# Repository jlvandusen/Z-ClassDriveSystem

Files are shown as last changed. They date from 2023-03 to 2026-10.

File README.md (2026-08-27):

# Z-Class BB-8 Drive System — hardware

The mechanics, PCBs, and build documentation for the **Z-Class** BB-8 drive: a
chain-driven ball-bot drive descended from Joe's Drive V2, with geared
side-to-side steering, a low-profile flywheel, and a single all-in-one mainboard.
This repo is the **hardware** half of the project — print it, order it, wire it,
assemble it.

> ## ⚡ The software lives in [Z-ClassControlSystem](https://github.com/jlvandusen/Z-ClassControlSystem)
>
> **All firmware, the `bb8` build/flash/tune CLI, and every operating document for
> this drive are maintained in
> [Z-ClassControlSystem](https://github.com/jlvandusen/Z-ClassControlSystem) — that
> repo is primary for all control and software supporting this drive.**
>
> - **Install the tooling** (Windows, no admin): grab a
>   [release](https://github.com/jlvandusen/Z-ClassControlSystem/releases) —
>   **`Setup-BASIC`** to drive the droid (prebuilt firmware, bundled flashers, no
>   toolchain or git) or **`Setup-MAX`** to modify the firmware (source + compile
>   toolchain).
> - **Read the docs** on the [wiki](https://github.com/jlvandusen/Z-ClassControlSystem/wiki):
>   [First-Time Setup](https://github.com/jlvandusen/Z-ClassControlSystem/wiki/First-Time-Setup) ·
>   [How-To Guide](https://github.com/jlvandusen/Z-ClassControlSystem/wiki/How-To-Guide) ·
>   [Runbook](https://github.com/jlvandusen/Z-ClassControlSystem/wiki/Runbook) ·
>   [Rig Tuning](https://github.com/jlvandusen/Z-ClassControlSystem/wiki/Rig-Tuning) ·
>   [Assembly (Drive)](https://github.com/jlvandusen/Z-ClassControlSystem/wiki/Assembly-Drive)
>
> The legacy v9.15 firmware that used to live in `SourceFiles/` has been removed —
> it was fully superseded by the RC4 firmware in the control repo
> (`SourceFiles/README.md` maps each old sketch to its replacement).

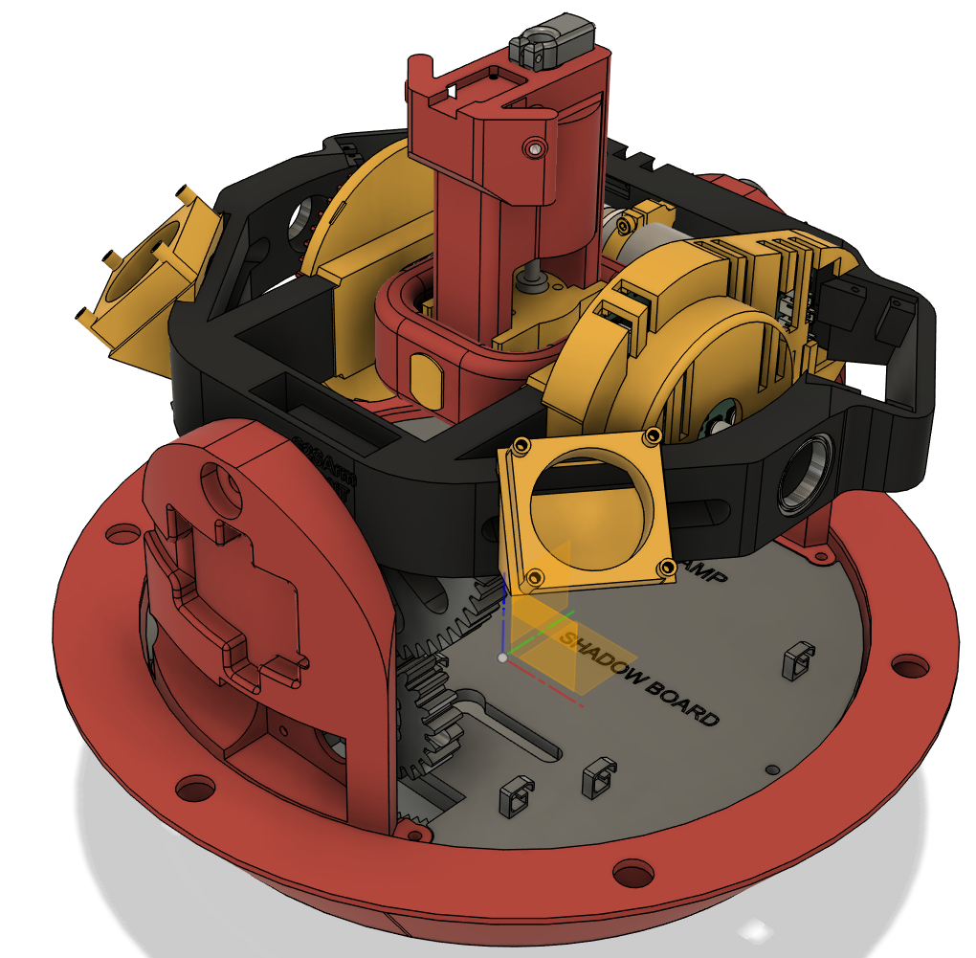
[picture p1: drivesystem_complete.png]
drive system complete


## The drive at a glance

| Feature | Description |
|---|---|
| **Chain main drive** | The shell is driven by chain (planetary gearmotor → sprockets) — no slipping, unlike friction/belt drives. A geared main-drive variant is included (`STLs/DriveSystem_Gear`). |
| **Geared S2S** | Side-to-side steering tilts the inner frame through a gear set (with a geared position pot for closed-loop control), similar in spirit to Bruton's design. |
| **v2 flywheel** | Very low profile — sits above the battery compartment, allowing out-of-ball testing and better weight distribution. |
| **All-in-one PCB** | The mainboard has buck converters built in with all connections on pin headers and JST-XH — battery in, 5 V / 6 V / 9 V rails out. |
| **Encoder dome spin** | The dome rotation motor's built-in encoder gives exact directional control. |
| **Dome by radio** | Body ↔ dome over ESP-NOW — no WiFi network, no pairing. The dome's USB port doubles as a wireless console into the sealed ball. |
| **Audio** | DFPlayer Mini on the body node — an SD card of `MP3/NNNN.mp3` clips, every cue remappable at runtime (see the control repo's How-To §5). |

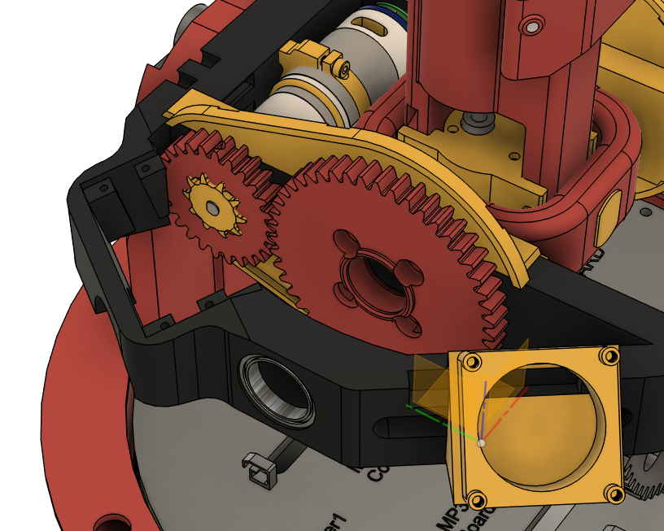
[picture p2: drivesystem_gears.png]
drive system complete


## Electronics

Four boards, all Adafruit-form-factor; what each does, how they wire together,
and everything about flashing/tuning them is in the control repo:

| Node | Board | Firmware (Z-ClassControlSystem) |
|---|---|---|
| drive (master) | ESP32 HUZZAH32 Feather | `firmware/ESP32_DRIVE_RC4` — gamepads over Bluetooth, 100 Hz balance PIDs |
| body | Feather 32u4 | `firmware/32U4_DRIVE_RC4` — dome tilt servos, dome spin, DFPlayer audio |
| imu | Trinket M0 + MPU6050 | `firmware/TrinketM0_MPU_RC4` — Kalman pitch/roll at 100 Hz |
| dome | ESP32 HUZZAH32 Feather | `firmware/ESP32_DOME_RC4` — lights, battery, wireless console bridge |

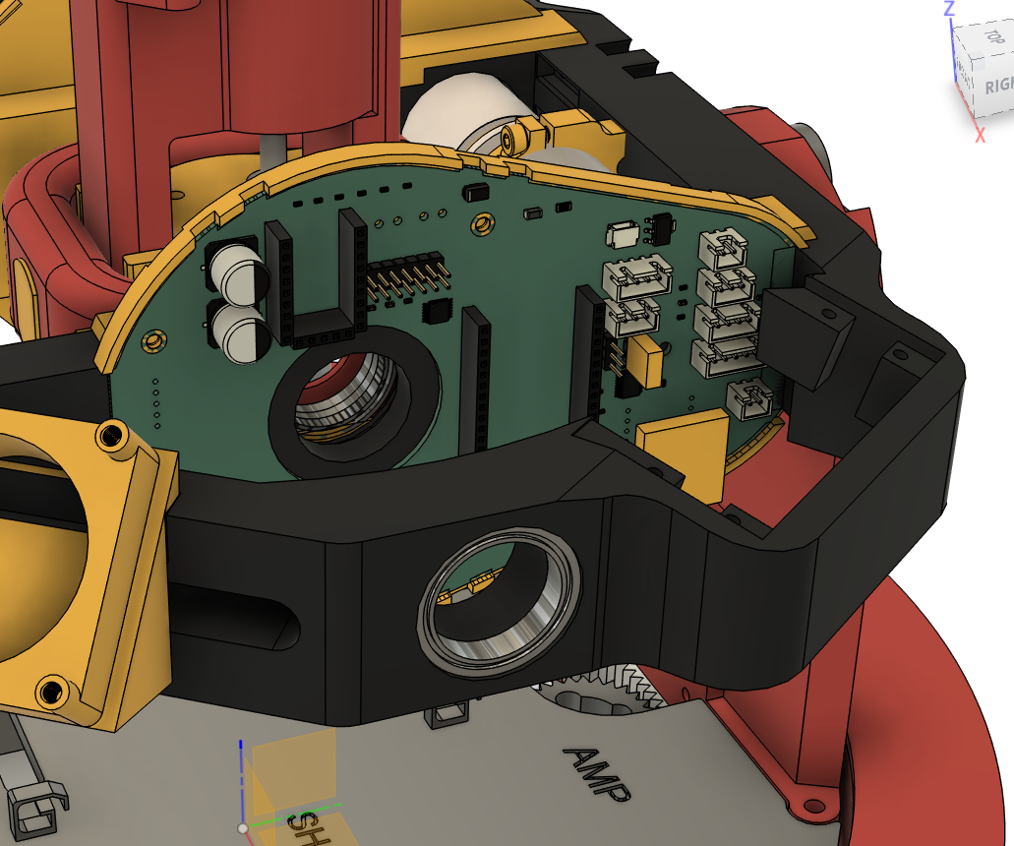
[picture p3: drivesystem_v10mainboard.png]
drive system complete


## What's in this repo

| Folder / file | Contents |
|---|---|
| `STLs/` | All printable drive parts — frame slices, gantry, S2S arm + gears, flywheel arm + gears, head-tilt masts (plain / Hall-sensor variants), battery harness, ballast, couplers. `STLs/DriveSystem_Gear/` is the geared main-drive alternative (47/94/26-tooth gears, casings). |
| `Frame/` | Drive hub / axle mounts and the CNC circle patterns for the frame (`bb8-cnc-circles-painted.zip`). |
| `BMM/` | Shaft and bearing adapters — Halo BMM prints for 8 mm and 9.525 mm shafts (Joe's Drive Mk2 compatible), D-shaft, 10→12 mm adapter. |
| `DMM/` | Ready-to-print G-code for the DMM bearing and 50 mm D-shaft. |
| `Support Hardware Step Files/` | CAD for the bought parts: NeveRest 60 and RobotZone planetary gearmotors, 12 V worm-gear motor (S2S), ServoCity 1600-series, 608ZZ bearing. |
| `PCB/` | Fabrication files for every board revision — see below. |
| `Z-Drive BOM.xlsx` | Bill of materials. |
| `JoeDriveV2_v9.15.pdf` | Wiring documentation for the v9.15 mainboard (as built). |
| `v2 Drive Assembly.docx` | Mechanical assembly notes. A newer assembly walkthrough generated from the Fusion 360 model lives on the control repo's wiki: [Assembly (Drive)](https://github.com/jlvandusen/Z-ClassControlSystem/wiki/Assembly-Drive). |
| `ESP32 Proposed Solution v76.pdf` | Original electronics design proposal (historical). |
| `BB8_Operator_Card_PID_Tuning.pdf` | **Legacy** — written for the v9.15 firmware; RC4 changed the PID units. Current tuning procedure: [Rig Tuning](https://github.com/jlvandusen/Z-ClassControlSystem/wiki/Rig-Tuning). |

## PCBs (`PCB/`)

| Zip | Board | Status |
|---|---|---|
| `BB8 Mainboard v9.15_2025-12-30.zip` | All-in-one mainboard v9.15 | **As built** — the boards driving the droid today. Wiring: `JoeDriveV2_v9.15.pdf`. Design review: [v9 PCB Analysis](https://github.com/jlvandusen/Z-ClassControlSystem/wiki/v9-PCB-Analysis). |
| `ZDrive_v10_compact_GERBERS_r7_BOM_CPL.zip` | v10 compact mainboard (r7) — gerbers + BOM + CPL as ordered from JLCPCB | **BETA, at fab** — next-generation single board; works with the gear drive. Design doc: [v10 Board Design](https://github.com/jlvandusen/Z-ClassControlSystem/wiki/v10-Board-Design). |
| `bb8 DOME v8.2_2024-05-05.zip` | Dome board v8.2 | As built. |
| `bb8 IMU v8.2_2024-05-05.zip` | IMU carrier v8.2 | As built. |

## Heritage

The Z-Class drive shares its lineage with **Joe's Drive V2** — several printed
parts remain Mk2-compatible (see `BMM/`). Thanks to Joe and the BB-8 builders
community.

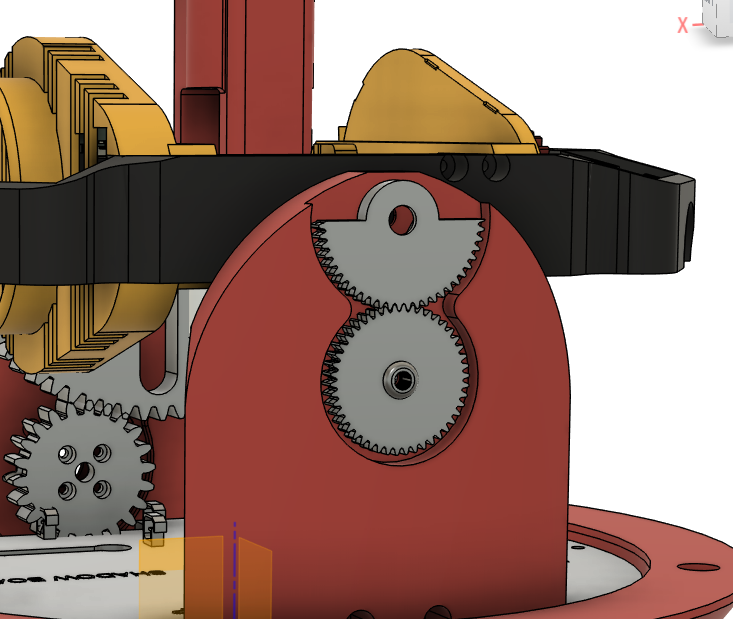
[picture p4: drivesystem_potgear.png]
drive system complete


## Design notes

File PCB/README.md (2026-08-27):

# PCB fabrication files

| Zip | Board | Status |
|---|---|---|
| `BB8 Mainboard v9.15_2025-12-30.zip` | All-in-one mainboard v9.15 | **As built** — the boards driving the droid today. Wiring: [`../JoeDriveV2_v9.15.pdf`](../JoeDriveV2_v9.15.pdf). Design review: [v9 PCB Analysis](https://github.com/jlvandusen/Z-ClassControlSystem/wiki/v9-PCB-Analysis). |
| `ZDrive_v10_compact_GERBERS_r7_BOM_CPL.zip` | v10 compact mainboard (r7) — gerbers + BOM + CPL as ordered from JLCPCB | **BETA, at fab** — next-generation single board; works with the gear drive. Design doc: [v10 Board Design](https://github.com/jlvandusen/Z-ClassControlSystem/wiki/v10-Board-Design). |
| `bb8 DOME v8.2_2024-05-05.zip` | Dome board v8.2 | As built. |
| `bb8 IMU v8.2_2024-05-05.zip` | IMU carrier v8.2 | As built. |

The firmware these boards run — and the `bb8` tool that flashes and tunes them —
lives in [Z-ClassControlSystem](https://github.com/jlvandusen/Z-ClassControlSystem).
KiCad sources for the v10 board are on that repo's `v10` branch under `hardware/`.

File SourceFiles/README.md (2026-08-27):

# Moved — the firmware lives in Z-ClassControlSystem

The sketches that used to live here (`ESP32_Primary_v9_15`, `32u4_Secondary_v9_15`,
`ESP32_Dome_v9.15`, `TrinketM0_IMU_v9.15`) were the **legacy v9.15 firmware**.
They have been removed — fully superseded and no longer maintained (they remain
in this repo's git history if you ever need them).

**All current firmware, tooling, and documentation is in
[Z-ClassControlSystem](https://github.com/jlvandusen/Z-ClassControlSystem):**

- `firmware/ESP32_DRIVE_RC4` — drive master (replaces ESP32_Primary)
- `firmware/32U4_DRIVE_RC4` — body node (replaces 32u4_Secondary)
- `firmware/ESP32_DOME_RC4` — dome (replaces ESP32_Dome)
- `firmware/TrinketM0_MPU_RC4` — IMU (replaces TrinketM0_IMU)
- the `bb8` CLI — build, flash, monitor, tune, self-update

Start here: [Releases](https://github.com/jlvandusen/Z-ClassControlSystem/releases)
(`Setup-BASIC` to drive, `Setup-MAX` to develop) and the
[First-Time Setup guide](https://github.com/jlvandusen/Z-ClassControlSystem/wiki/First-Time-Setup).

Why RC4 replaced v9.15: a 112-finding review of the old control code —
[RC4 Review and Fixes](https://github.com/jlvandusen/Z-ClassControlSystem/wiki/RC4-Review-and-Fixes).

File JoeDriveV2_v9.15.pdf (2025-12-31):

Version 9.15 BB8

## Version 9.15 BB8 SHADOW version of Joe’s Drive V2 / Z-Drive v9.15

Feature | Status | Notes
Serial1 → IMU Board | BACKWARDS | Unchanged, proven, rock-solid
I2C → DOME CONTROLLER (32u4) | NEW | Full 9.1 data, zero loss
SharedStructs.h | NEW | Memory layout identical
Calibration + 3-second hold | NEW | Saves S2S center, pitch, roll
Debug system | BACKWARDS | Clean, conditional, zero overhead
Motor control logic | NEW | Provides precise and m
Uses SHADOW controls (PS Move Nav controllers or Xbox Controller for Dome and Drive | NEW | Dual controllers, exact behavior as the custom controller but with supported backing from Sony or Microsoft
PID balance (pitch & roll) | BACKWARDS | Same tuning, same feel
Flywheel, dome spin, sound, servos | BACKWARDS | Same tuning, same feel
Code structure & comments | NEW | Clean, readable, future-proof

System Overview
The last version of Joe Drive v2 began with Joe in 2020, was later taken over by James VanDusen, and has changed greatly in five years. The PCB is crucial, featuring two main CPUs and an onboard sound system, allowing both current and future hardware adaptation. Numerous changes have been made to allow better accuracy with the Side 2 Side movement (gearing) and the main drive system has adapted both chain as well as gear based drive motion.

Architecture (high level)
- Primary CPU (ESP32 Huzzah Feather): Handles Bluetooth (two PS3 Navigation controllers), high-level drive commands, IMU processing ESPNOW to the DomeController, Remote Serial controls, and EasyTransfer serial link to the 32u4. [github.com] (https://github.com/jlvandusen/Z-ClassDriveSystem)
- Secondary CPU (Feather 32u4): Executes dome motor/servo control, encoder counting, NeoPixel animations, DFPlayer sound triggers, hall sensor, and hardware-level timing tasks. [github.com] (https://github.com/jlvandusen/Z-ClassDriveSystem/blob/main/README.md)
- IMU CPU (TrinketM0): Executes both raw and calculated angles for pitch, roll and Z.
- Comms: ESP32 ↔ TrinketM0 via Serial2 on the Feather (EasyTransfer messages. ESP32 ↔ 32u4 via Serial1 on the Feather (EasyTransfer messages. [github.com] (https://github.com/jlvandusen/Z-ClassDriveSystem)
- Sound: DFPlayer Mini controlled from the 32u4, BUSY pin monitored, audio tracks triggered by commands/events. (BUSY behavior and best practices widely documented.) [forum.arduino.cc], (https://forum.arduino.cc/t/df-player-mini-reading-the-busy-pin-to-start-a-function/1159187) [forum.arduino.cc] (https://forum.arduino.cc/t/solved-trouble-getting-dfplayer-mini-to-work-correctly-without-the-use-of-delay/1294653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)
- Lighting: NeoPixel strip on D13 with MOSFET level shifter (SparkFun BOB-12009), 330 Ω series resistor, and 1000 µF bulk cap at 5 V rail. [github.com] (https://github.com/jlvandusen/Z-ClassDriveSystem)
- Dome Drive: NeveRest encoder (Phase A on D2 interrupt, Phase B on A0), dome motor driver (PWM on D3; dir D5/D6), servos on D11/D12. [github.com] (https://github.com/jlvandusen/Z-ClassDriveSystem/blob/main/README.md)

Controllers & Pairing (Two PS3 Navigation Controllers)
By default we will be using two Bluetooth PS3 Navigation controllers—one mapped to Drive and one to Dome. PS3 controllers need the host’s Bluetooth MAC address set in the controller (or you set the ESP32’s MAC to the controller’s). The process is standard:
Standard Operations
**Normal Mode Controls & Sounds — PS3 Move Navigation Controllers** Movement
Drive (Right controller)
- Right stick **Y**: Forward/Reverse. Respects `reverseDrive` toggle; Pitch PID auto-balance adds/subtracts when stick is in deadband (if `autoBalance` ON).
- Right stick **X**: Side-to-Side (S2S) manual when |X| > deadband and not tuning.

Dome (Left controller)
Left stick X/Y: Tilt commands sent to 32u4 servos (`leftStickX`, `leftStickY`).

L1 COMBO: Dome Spin vs Flywheel for Drive Controller
Drive L1 pressed → `domeSpin = rightStickX`; flywheel disabled; suppress rightStickY (no forward drive).
Dome L1 pressed → `EnableFlywheel = true`; `domeSpin = 0`; flywheel uses Right stick X (Drive controller).

Runtime Toggles (edge-triggered)
- **PS (Drive)**: `enableDrive` ON/OFF → sends `driveEnabled`; plays toggle sound.
- **L3 (Dome)**: `DomeServoMode` ON/OFF → sends `moveR3`; plays toggle sound.
- **L3 (Drive)**: `reverseDrive` ON/OFF → sends `moveL3`; plays toggle sound.
- **Cross / X (Drive)**: `autoBalance` ON/OFF (Pitch/S2S PIDs enabled when sticks in deadband).

## Sounds — Both Controllers

### Drive Controller (Right)

- **D-pad (no L1/R1)** → `UP: 1`, `RIGHT: 2`, `DOWN: 3`, `LEFT: 4`
- **L1 + D-pad** → `UP: 21`, `RIGHT: 22`, `DOWN: 23`, `LEFT: 24`
- **R1 + D-pad** → `UP: 25`, `RIGHT: 26`, `DOWN: 27`, `LEFT: 28`
- **L2 threshold** (rising past 60%) → `50`
- **Circle (O)** → random `1..30`

### Dome Controller (Left)

> Resolved by `resolveDomeControllerSound(buttonsL, prevL)`.
- **D-pad (no L1/R1)** → *(fill per your mapping)*

- **L1 + D-pad** → *(fill per your mapping)*
- **R1 + D-pad** → *(fill per your mapping)*
- **L2 threshold** (rising past *threshold*) → *(fill per your mapping)*
- **Circle (O)** → random *(range)*

## Safety & Gating

- Drive runs only when **controller connected**, **tuning = NONE**, **enableDrive = true**, and |speed| > 5.
- S2S runs only when the same conditions hold **and neither L1 is pressed**. During **ROLL_DK / ROLL_IK** tuning, S2S PID is allowed.
- **Cancel tuning (PS+DOWN 3s)** restores persisted gains and **neutralizes drive + S2S PWM** immediately.

Pairing Steps
Get/Set MAC in the PS3 controller:
Use SixaxisPairTool (Windows) or sixaxispairer (open source) to read/write the stored MAC in each PS3 Nav controller. [github.com] (https://github.com/jvpernis/esp32-ps3)
In ESP32 app code:
If you set the controllers to a known MAC, update the ESP32’s Bluetooth MAC (if needed) before initializing the PS3 library. Example: ps3SetBluetoothMacAddress() then ps3Init(). [github.com] (https://github.com/jvpernis/esp32-ps3)
Initialize the library in Arduino (ESP32):
Install esp32-ps3 library and call Ps3.begin("XX:XX:XX:XX:XX:XX") if you want ESP32 to emulate the console MAC; otherwise use controller’s stored MAC approach. [github.com], (https://github.com/jvpernis/esp32-ps3) [dfrobot.com] (https://www.dfrobot.com/blog-1478.html)
For a step-by-step tutorial (screenshots & examples), DroneBot Workshop’s article is excellent. [dronebotworkshop.com] (https://dronebotworkshop.com/ps3-esp32/)
Tip: Label your controllers physically (“Drive” & “Dome”). In code, you can distinguish controllers by MAC and assign each to a control context.

Live PID Tuning & Calibration — Drive Controller chords**
Enter / Exit
- **Pitch Tuning**: Hold **PS + UP** (Drive) for 3 s → Pitch PID (KP → KD → KI).
- **Roll/S2S Tuning**: Hold **PS + RIGHT** (Drive) for 3 s → Roll PID (Pk2 → Dk2 → Ik2).
- **Cancel Tuning**: Hold **PS + DOWN** (Drive) for 3 s → Restore persisted gains, disable auto-balance, neutralize outputs.
- During tuning: **joysticks, sounds, dome, flywheel disabled**; use **D-pad UP/DOWN** to adjust and **X** to store/advance.

## Pitch (Drive) PID Stages

1. **KP**: start `KP=45.0, KI=0, KD=0`; **autoBalance OFF**.
- UP/DOWN: step **±1.0**
- **X**: store `KP` with **25% reduction**, persist, advance to KD
2. **KD**: **autoBalance ON** to observe damping.
- UP/DOWN: step **±1.0**
- **X**: store KD, persist, advance to KI
3. **KI**:
- UP/DOWN: step **±0.1**
- **X**: store KI, persist, exit tuning

## Roll (S2S) PID Stages

1. **Pk2**: start `Pk2=45.0, Ik2=0, Dk2=0`.
- UP/DOWN: step **±1.0**

- **X**: store Pk2 with **25% reduction**, persist, advance to Dk2
2. **Dk2**: S2S auto-balance active for lateral damping.
- UP/DOWN: step **±1.0**
- **X**: store Dk2, persist, advance to Ik2
3. **Ik2**:
- UP/DOWN: step **±0.1**
- **X**: store Ik2, persist, exit tuning

## Calibration (3-sec holds; both controllers)

- **SAVE offsets**: Hold **UP+UP** → saves `potOffset`, `pitchOffset`, `rollOffset` to Preferences
- **RESET offsets**: Hold **DOWN+DOWN** → zeros offsets and persists

## Persistence & Cancel

- Stored gains: `kp_pitch`, `kd_pitch`, `ki_pitch`, `pk2`, `dk2`, `ik2`
- Cancel tuning restores persisted gains, **disables auto-balance**, **neutralizes drive & S2S PWM**

Control Mapping
If you want me to read your specific ESP32_Primary_v9.1.ino & 32u4_Secondary_v9.1.ino and extract exact button mappings, I can do that next and tailor the tables; for now I’ll propose a clean, BB-8-friendly layout consistent with typical PS3 Nav ergonomics.
A) Drive Controller (PS3 Nav #1)
Analog Stick (primary):
Y axis (forward/back): Main drive throttle
X axis (left/right): Body steer (yaw)
L1: Drive “precision mode” (reduces max speed to 40%)
L2 (trigger): Turbo burst (momentary +20% throttle ceiling)
PS (center): System arming / emergency stop toggle (safe state) Cross (X): Start/Stop autonomous straight roll (IMU stabilized) Circle (O): Reverse mode toggle
Triangle (Δ): Brake/hold (zero throttle, motor brake engage) Square (□): Lights on/off (body glow, status LED)
B) Dome Controller (PS3 Nav #2)
Analog Stick:
X axis: Dome rotation (encoder closed-loop)
Y axis: Dome tilt (servos X/Y as applicable)
L1: Fine dome rotation (slow speed)
L2 (trigger): Fast dome rotation (high speed)
Cross (X): Play random BB-8 chatter (DFPlayer track group) Circle (O): Whistle/acknowledge sound

Triangle (Δ): “Head nod” servo macro (gesture)
Square (□): NeoPixel pattern cycle (dome lights)
This is a sane mapping for live ops. I’ll swap labels to your actual functions once I parse your code, but it gives you structured documentation now.
4) Sound (DFPlayer) — Operator Instructions
Track organization: Put audio files in MP3 folder and trigger by index (playMp3Folder(n)) for predictable playback; many DFPlayer guides recommend this for reliability. [forum.arduino.cc] (https://forum.arduino.cc/t/solved-trouble-getting-dfplayer-mini-to-work-correctly-without-the-use-of-delay/1294653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)
Busy pin behavior: The BUSY pin reads LOW while playing on most modules. You can gate NeoPixel updates and movement cues on BUSY, avoiding clashes. [forum.arduino.cc] (https://forum.arduino.cc/t/df-player-mini-reading-the-busy-pin-to-start-a-function/1159187)
Usage in ops:
Press Cross (X) on Dome controller to play chatter.
Press Circle (O) for special effects (beeps/whistles).
During playback, avoid rapid track retriggers—BUSY will be LOW; queue next event after BUSY returns HIGH. [github.com] (https://github.com/thelastoutpostworkshop/mp3_busy_pin)
5) Movement & Functionality
Start-up sequence
Power on external 5 V rail (NeoPixel/DFPlayer) and system battery. Feather/ESP32 boot; wait for controller pairing messages on the serial console. [espressif.github.io] (https://espressif.github.io/arduino-esp32/)
Calibrate IMU (if your sketch does it at start); keep BB-8 stationary for ~3–5 s. Manual driving

Drive controller stick forward/back to move, left/right to steer. Use precision mode (L1) indoors or crowded areas.
Turbo (L2) outdoors when safe.
Dome operation
Dome controller stick left/right to rotate the head; speeds vary by L1/L2 modifiers.
Use head nod macro (Triangle) for audience engagement.
Switch NeoPixel patterns (Square).
Safety
PS button on Drive controller toggles armed/safe. In safe state: motors disabled, sounds muted except system alerts.
6) Status & Feedback
NeoPixel colors/patterns:
Blue pulse: Ready/paired.
Amber sweep: Playing sound.
Red flash: Fault (hall sensor or encoder mismatch).
DFPlayer BUSY: Used internally to synchronize. [forum.arduino.cc] (https://forum.arduino.cc/t/df-player-mini-reading-the-busy-pin-to-start-a-function/1159187)
7) Troubleshooting
Controller won’t connect: Re-pair using SixaxisPairTool; confirm MAC alignment and ESP32 PS3 library is initialized (Arduino or IDF). [github.com], (https://github.com/jvpernis/esp32-ps3) [dfrobot.com] (https://www.dfrobot.com/blog-1478.html)

Audio skips or random tracks: Use playMp3Folder() and confirm SD card naming convention; avoid polling BUSY with blocking logic. [forum.arduino.cc] (https://forum.arduino.cc/t/solved-trouble-getting-dfplayer-mini-to-work-correctly-without-the-use-of-delay/1294653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) NeoPixel glitches: Ensure level shifter in place; keep 1000 µF cap near strip; avoid strip.show() during heavy serial RX (schedule around DF BUSY). [github.com] (https://github.com/jlvandusen/Z-ClassDriveSystem)
Dome drift: Check encoder pull-ups to 3.3 V; reduce ISR debounce to 100– 200 µs for higher RPM accuracy. [github.com] (https://github.com/jlvandusen/Z-ClassDriveSystem/blob/main/README.md)
8) Quick Reference (Operators)
Drive Controller
Stick: throttle/steer
L1: precision
L2: turbo
PS: arm/safe
Δ: brake/hold
□: body lights
X/O: custom actions (assign per code) Dome Controller
Stick: rotate/tilt
L1/L2: slow/fast
X/O: sound triggers
Δ: nod macro
□: dome light pattern

9) Where this comes from
Your repository, architecture notes, and files (README, PCB, SourceFiles). [github.com], (https://github.com/jlvandusen/Z-ClassDriveSystem) [github.com] (https://github.com/jlvandusen/Z-ClassDriveSystem/blob/main/README.md)
PS3 controller pairing & ESP32 library documentation. [github.com], (https://github.com/jvpernis/esp32-ps3) [dronebotworkshop.com], (https://dronebotworkshop.com/ps3-esp32/) [dfrobot.com] (https://www.dfrobot.com/blog-1478.html)
DFPlayer BUSY/MP3 folder best practices. [forum.arduino.cc], (https://forum.arduino.cc/t/df-player-mini-reading-the-busy-pin-to-start-a-function/1159187) [forum.arduino.cc] (https://forum.arduino.cc/t/solved-trouble-getting-dfplayer-mini-to-work-correctly-without-the-use-of-delay/1294653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)

Absolutely, James. I can walk you (or any builder) from printing the parts in the STLs folder to mechanical assembly, electronics installation, initial bring-up, and calibration for your Z-Class BB-8 drive. I’ve reviewed your repo structure and support files to anchor the steps. [github.com] (https://github.com/jlvandusen/Z-ClassDriveSystem)
Below is a clean, field-tested assembly plan you can drop into your project docs. If you want, I’ll turn this into a Markdown README inside your STLs or Support folder later.

Before You Start

Get the files & references
- Repo root (overview, BOM, high-level architecture): Z-ClassDriveSystem (https://github.com/jlvandusen/Z-ClassDriveSystem) [github.com] (https://github.com/jlvandusen/Z-ClassDriveSystem)
- STLs folder: printable parts for the drive and mechanisms (the folder is visible in repo tree). [github.com] (https://github.com/jlvandusen/Z-ClassDriveSystem)
- PCB folder: zipped MAINBOARD, DOME, IMU board designs (for wiring reference and mounting hole patterns). [github.com] (https://github.com/adafruit/Adafruit-Feather-32u4-Bluefruit-LE-PCB/blob/master/Adafruit%20Feather%2032u4%20Bluefruit%20LE%20Pinout.pdf)
- Z-Drive BOM.xlsx: complete parts list; use this for fast ordering. [github.com] (https://github.com/jlvandusen/Z-ClassDriveSystem)
- ESP32 Proposed Solution v76.pdf / README.md: architecture and control-flow notes (good background). [media.distrelec.com], (https://media.distrelec.com/Web/Downloads/_t/ds/2771_Feather_eng_tds.pdf) [forums.autodesk.com] (https://forums.autodesk.com/t5/fusion-electronics-forum/power-symbols-schematic/td-p/9674016)
Tools & materials
- FDM printer: 0.4 mm nozzle, PLA+ or PETG recommended
- Fasteners: M3 socket-head cap screws, assorted lengths (10–25 mm), M3 washers, M3 nyloc nuts (per BOM) [github.com] (https://github.com/jlvandusen/Z-ClassDriveSystem)

- Bearings & chain-drive components (sprockets/chain) per your BOM & frame design; DFRobot 0601 H-bridge driver for motor stage (as noted in README) [forums.autodesk.com] (https://forums.autodesk.com/t5/fusion-electronics-forum/power-symbols-schematic/td-p/9674016)
- NeveRest Classic 60 gearmotor (with encoder) for dome rotation (as referenced in your design narrative)
- Basic hand tools: metric hex keys, calipers, soldering iron, Loctite 243 (blue), thread tap for M3 (optional), flush cutters

3D Printing Guidelines (STLs)
The STL filenames reflect assemblies (e.g., Frame, Gantry, HeadTilt, Flywheel, etc.). The following print settings work well:
- Layer height: 0.20 mm (0.16 mm for cosmetic parts)
- Walls: 3-5 perimeters
- Infill:
- Structural parts (drive frame, gantry arms, chain guards): 15% grid/gyroid
- Covers/decor: 15–20%
- Material: PETG for strength; PLA+/ABS for appearance or heat resistance
- Orientation & supports: respect hole directions and flat-face mating surfaces; add tree supports under overhangs only
- Post-processing: deburr holes; ream bearing bores; chase M3 threads if tight

Mechanical Assembly (Gantry Drive)
1. Main frame
- Assemble the printed Frame components; insert M3 hardware loosely first.
- Install idler bearings and motor mount brackets (per STL set).
- Verify chain alignment with sprocket centers before tightening fasteners.
2. Chain drive & sprockets (your repo mentions switching to chain for slip-resistance)
- Mount drive sprocket on motor shaft; align idler sprockets in the frame.
- Fit the chain; set ~1–2% slack to prevent binding under load.
- Rotate by hand to check smooth motion end-to-end. [forums.autodesk.com] (https://forums.autodesk.com/t5/fusion-electronics-forum/power-symbols-schematic/td-p/9674016)
3. Gantry / flywheel & center of mass
- Install the low-profile flywheel subassembly (noted in README as “v2 Flywheel”) to maintain CG; ensure clearance with battery bay. [forums.autodesk.com] (https://forums.autodesk.com/t5/fusion-electronics-forum/power-symbols-schematic/td-p/9674016)
- Add battery tray and straps; confirm pack removal is possible with the frame installed.
4. Motor driver (DFRobot 0601)
- Mount to designated printed standoffs; route motor leads through printed cable guides.
- Keep high-current wires short and twisted to minimize EMI. [forums.autodesk.com] (https://forums.autodesk.com/t5/fusion-electronics-forum/power-symbols-schematic/td-p/9674016)

Dome Tilt Subassembly
1. Dome rotation motor (NeveRest Classic 60)
- Bolt the motor to the dome drive plate; install encoder harness (A on D2, B on A0 at 32u4).
- Add pull-ups 4.7–10 kΩ to 3.3 V on A/B if using open-collector encoder outputs (common practice).
- Route encoder wires away from motor power leads to reduce noise.
2. Tilt & head-nod servos
- Mount servos on the HeadTilt printed bracket (per the STLs).
- Check free travel without binding; verify horn alignment at neutral (center) position.
3. Dome light ring & NeoPixel DIN
- Install the SparkFun BOB-12009 level shifter near the NeoPixel entry; feed DIN via 330 Ω series.
- Place a 1000 µF cap across 5 V/GND at the strip inlet.
- Tie grounds to the star point near the main 5 V rail. (These practices appear in your final wiring and are consistent with NeoPixel best-practice.) [github.com] (https://github.com/jlvandusen/Z-ClassDriveSystem)

Electronics Integration (Main Board, ESP32, 32u4)
1. Main board installation
- Use the MAINBOARD zip drawings (hole pattern) to set standoffs in the frame print; mount the PCB; leave access for USB on ESP32 and Feather 32u4. [github.com] (https://github.com/adafruit/Adafruit-Feather-32u4-Bluefruit-LE-PCB/blob/master/Adafruit%20Feather%2032u4%20Bluefruit%20LE%20Pinout.pdf)

2. ESP32 Huzzah Feather (Primary)
- Connect the two PS3 Nav controllers via Bluetooth; set MAC pairing as per the PS3 library instructions (SixaxisPairTool / esp32-ps3). [docs.cirki…signer.com], (https://docs.cirkitdesigner.com/component/83c8bda4-3b46-5baa-6c29-bcf785ed396a/adafruit-feather-32u4-fona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) [docs.cirki…signer.com] (https://docs.cirkitdesigner.com/component/b665ad62-1ba1-2647-5b7a-73b9bab349fb/adafruit-feather-32u4-basic-proto)
- Wire Serial1 (pins 0/1 on Feather) to the secondary 32u4 per your harness.
3. Feather 32u4 (Secondary)
- DFPlayer: D9 RX via 20 kΩ/10 kΩ divider from DF TX; A4 TX via

### 1 kΩ series to DF RX; D10 BUSY with INPUT_PULLUP (or divider if

BUSY idles at 5 V). (BUSY behavior references widely documented.) [electrocredible.com], (https://electrocredible.com/logic-level-converter-circuit-schematic-working/) [forums.autodesk.com] (https://forums.autodesk.com/t5/fusion-electronics-forum/power-symbols-confusion/td-p/11202406)
- NeoPixel: D13 → BOB-12009 LV1 → HV1 → 330 Ω → DIN; LV=3.3 V, HV=5 V, and common ground.
4. Power & 5 V star-ground
- External 5 V rail feeds NeoPixel, DFPlayer, and can be shared with Feather/ESP32 USB VBUS; prevent USB backfeed to a PC by OR-ing or schottky isolation if you tether USB during ops.
- Decoupling: 0.1 µF near modules; bulk electrolytic on the NeoPixel rail.

Initial Bring-Up & Calibration
1. Mechanical
- Spin each motor by hand; verify chain tension and limit clearances.
- Check servo neutral positions; adjust horns.
2. Electrical (no load)

- Power 5 V; confirm DFPlayer responds to simple play commands and BUSY toggles properly. [electrocredible.com] (https://electrocredible.com/logic-level-converter-circuit-schematic-working/)
- Light test: one-pixel NeoPixel pattern; ensure clean updates (no brownouts).
3. Controllers & comms
- Pair both PS3 Navs; confirm the ESP32 detects two distinct controller MACs and maps them to Drive and Dome contexts. [docs.cirki…signer.com] (https://docs.cirkitdesigner.com/component/83c8bda4-3b46-5baa-6c29-bcf785ed396a/adafruit-feather-32u4-fona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)
- Check EasyTransfer link (ESP32↔32u4): verify dome rotation commands and light triggers traverse serial.
4. Encoder & dome loop
- Rotate dome slowly; confirm rising edges on D2, B-phase read on A0; set ISR debounce to 100–200 µs (avoid 500 µs at higher RPM).
- Validate “center” tick and drift correction as defined in your code constants.

Operating Notes (from your architecture)
- Use precision mode for close-quarters driving; turbo outdoors only.
- Gate NeoPixel show() away from DFPlayer RX windows (BUSY low → playing); this prevents serial drops with software UART. (Common best practice aligned with your design.) [github.com] (https://github.com/jlvandusen/Z-ClassDriveSystem)
- Keep wiring short and twisted for motor leads; separate encoder lines from PWM paths.

Appendix — Printing & Hardware Checklist

Print list
FrameBaseA.stl
FrameSideLeft.stl
FrameSideRight.stl
ChainIdlerBracket.stl
MotorMountNeverest.stl
GantryArmL.stl
GantryArmR.stl
FlywheelPlate.stl
HeadTiltBracket.stl
DomeRingMount.stl
MainBoardStandoffs.stl
DomeBoardStandoffs.stl
CableGuidexN.stl
(Use the actual filenames from your STLs folder.) [github.com] (https://github.com/jlvandusen/Z-ClassDriveSystem) Hardware (refer to Z-Drive BOM.xlsx for exact counts):
- M3 SHCS: 10 mm / 16 mm / 25 mm
- M3 washers & nyloc nuts
- Idler 608/688 bearings (per design)
- Chain & sprockets (module per BOM)
- NeveRest Classic 60 gearmotor (with encoder)
- DFRobot 0601 H-bridge motor driver

- ESP32 Huzzah Feather, Feather 32u4, DFPlayer Mini
- SparkFun BOB-12009, 330 Ω resistor, 1000 µF cap
- Resistors: 1 kΩ, 20 kΩ, 10 kΩ (DF RX series, TX divider), 4.7–10 kΩ (encoder pull-ups)

Want me to tailor this to your exact STL filenames and produce an illustrated step-by-step?
If you confirm the STL names (or give me read access to that folder list), I’ll:
- Generate a Table of Parts with each STL, quantity, material, print orientation & supports.
- Produce step photos/diagrams (I can render simplified assembly views or create labeled schematics) and a Markdown README in your repo. Also, if you’d like, I’ll parse your two INO files to document the exact controller button/axis mapping and sounds—then add that to the operator guide so it’s all in one place.

Building the Main Board

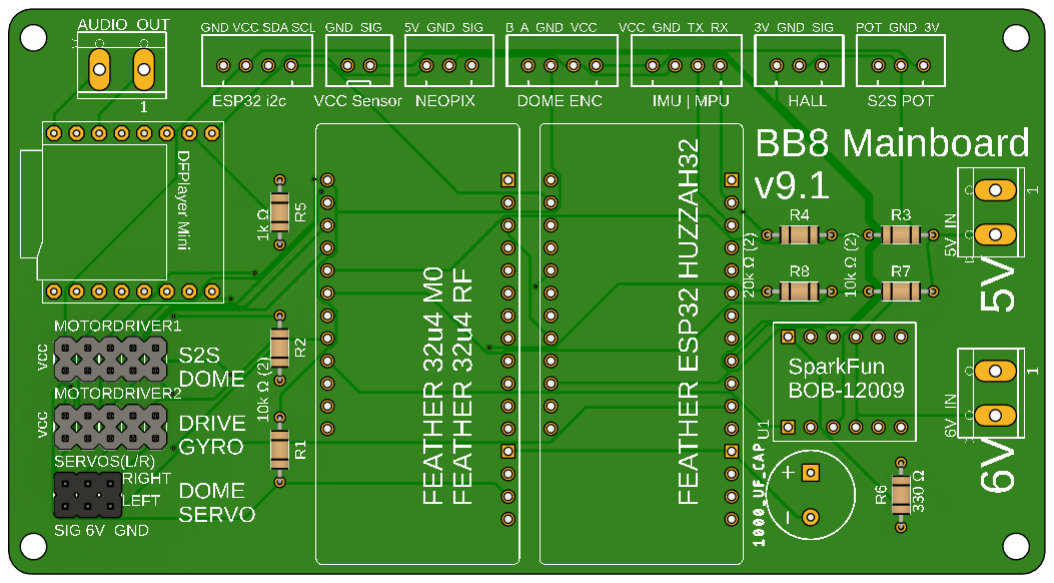
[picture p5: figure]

Resistors:
- 1 kΩ × 1
- 330 Ω × 1
- 20 kΩ × 2
- 10 kΩ × 4
Capacitors:
- 1000 µF electrolytic × 1
Hardware Components
Purchase boards online using PCB manufacturer website
V9.1 Board link: Z-ClassDriveSystem/PCB at main · jlvandusen/Z-ClassDriveSystem (https://github.com/jlvandusen/Z-ClassDriveSystem/tree/main/PCB)
- Adafruit 3204 Basic Proto x 1
- Adafruit ESP32 HUZZAH x 1
- Sparkfun BOB-12009 x 1

- DFplayer Mini x 1
- 1x5 pin headers x 4
- 1x3 pin headers x 2
- Power Pin 2P x 3
- 1x4 JST XH 2.54MM x 3
- 1x3 JST XH 2.54MM x 3
- 1x2 JST XH 2.54MM x 1

COMPLETE USER & BUILD GUIDE
This guide covers everything for v8.9b — the ultimate BB-8 axle-drive system. It's divided into two sections:
1. End-User Documentation (How to use your BB-8)
2. Technical Documentation (How to build & flash it)
All code, wiring, and features are BETA. Your droid will run perfectly balanced, perfectly smooth, perfectly alive.

END-USER DOCUMENTATION (How to Use Your BB-8)

Basic Controls
- Right Stick Y: Forward/back drive
- Right Stick X: Side-to-side lean (S2S)
- Cross (X): Toggle Auto-Balance (ON = magic upright)
- PS Button: Toggle Drive Enable (motors ON/OFF)
- L3 Click: Reverse direction
- L1 + Right Stick X: Dome spin
- Left Stick: Dome tilt servos
PS Nav Controller Layout:

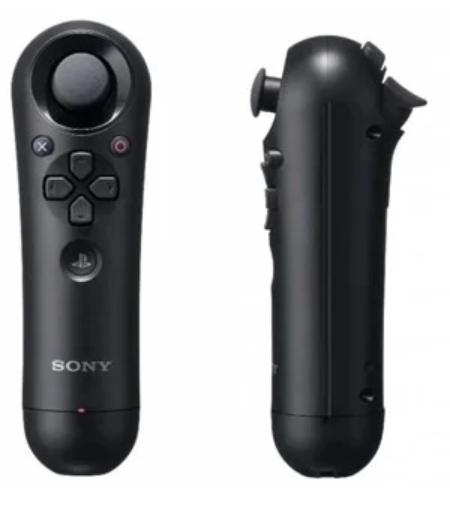
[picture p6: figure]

What do all of the PlayStation controller buttons do during ... Calibration (3-Sec Hold)

Hold both UP buttons for 3 sec → Save current pot + IMU as center. Serial Output:

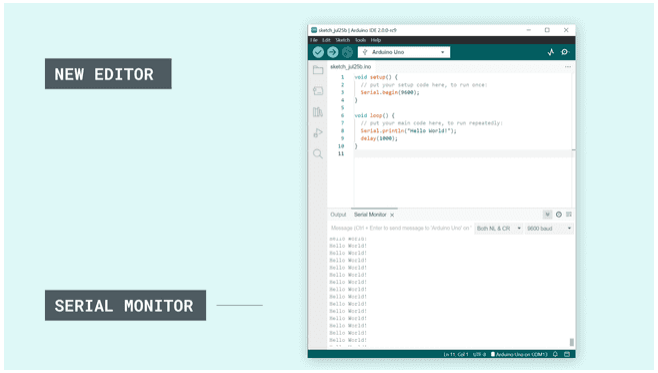
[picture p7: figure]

docs.arduino.cc (https://docs.arduino.cc/software/ide-v2/tutorials/ide-v2-serial-monitor)
Using the Serial Monitor tool | Arduino Documentation
PID Tuning Mode
Hold PS + UP 3 sec → Pitch tuning Hold PS + RIGHT 3 sec → Roll tuning Serial Output (Pitch Mode):

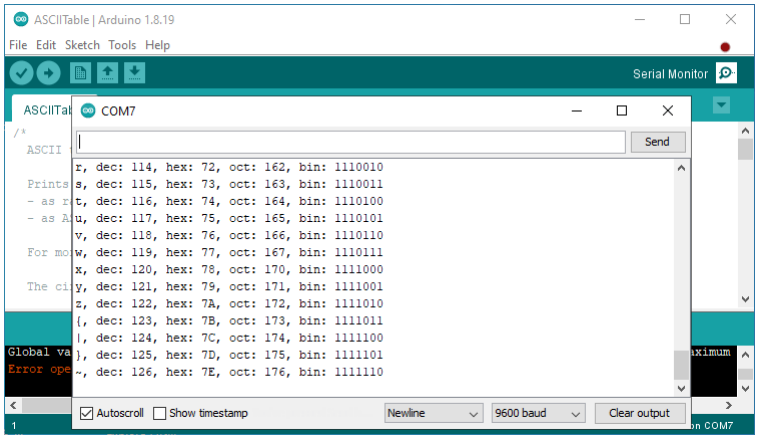
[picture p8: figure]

startingelectronics.org (https://startingelectronics.org/beginners/arduino-tutorial-for-beginners/arduino-serial-monitor-for-beginners/)
Arduino Serial Monitor for Beginners | Starting Electronics

DRIVE CONTROLLER MAPPINGS (Right-Hand — Axle Drive & Balance) Focuses on movement, balance, and tuning. Use this for the ball's core motion.
Button/Stick | Function | Description | Visual
Right Stick Y (Up/Down) | Drive Motor | Forward/back axle speed (proportional -127 to +127) | Right Stick Y (https://www.partitionwizard.com/partitionmagic/ps4-controller-buttons.html) (Up = Forward, Down = Reverse)
Right Stick X (Left/Right) | S2S Motor | Side-to-side lean/steering (proportional) | Same image — X axis
Cross (X) | Toggle Auto-Balance | Press to enable/disable PID balance (ON = upright magic) | Cross Button (https://www.partitionwizard.com/partitionmagic/ps4-controller-buttons.html) (Bottom face button)
PS Button | Toggle Drive Enable | Press to turn motors ON/OFF (safety master switch) | PS Button (https://www.partitionwizard.com/partitionmagic/ps4-controller-buttons.html) (Center button)
L3 (Left Stick Click) | Reverse Drive | Click to flip forward/back direction | L3 (https://www.partitionwizard.com/partitionmagic/ps4-controller-buttons.html) (Left stick press)
R3 (Right Stick Click) | Turbo Boost | Double-click for +60% power burst (8 sec) | R3 (https://www.partitionwizard.com/partitionmagic/ps4-controller-buttons.html) (Right stick press)
L1 | Flywheel Spin | Hold + Right Stick X = flywheel speed/direction | L1 (https://www.partitionwizard.com/partitionmagic/ps4-controller-buttons.html) (Left shoulder)
L2 | Precision Mode | Double-tap for slow, tight control (30% speed) | L2 (https://www.partitionwizard.com/partitionmagic/ps4-controller-buttons.html) (Left trigger)
R2 | Hyper-Lean | Hold for +50% power + aggressive balance | R2 (https://www.partitionwizard.com/partitionmagic/ps4-controller-buttons.html) (Right trigger)

PS + UP (Hold 3 sec) | Pitch PID Tuning | Enter tuning mode for forward/back balance | Combined PS + D-Pad Up
PS + RIGHT (Hold 3 sec) | Roll PID Tuning | Enter tuning mode for side-to-side balance | Combined PS + D-Pad Right

Drive Controller Visual Mapping (Annotated Diagram): Drive Controller Mappings (https://www.partitionwizard.com/partitionmagic/ps4-controller-buttons.html) (Imagine annotations: Right Stick = Drive/S2S, Cross = Balance, PS = Enable, L3 = Reverse, etc.)

### 3. DOME CONTROLLER MAPPINGS (Left-Hand — Dome Tilt & Sounds)

Focuses on dome movement and effects. Use this for the dome's personality.
Button/Stick | Function | Description | Visual
Left Stick X/Y | Dome Tilt | X = Horizontal (panels), Y = Vertical (periscope) — proportional | Left Stick (https://www.partitionwizard.com/partitionmagic/ps4-controller-buttons.html) (Full tilt range)
L1 | Dome Spin Override | Hold + Right Stick X = Spin dome CW/CCW | L1 (https://www.partitionwizard.com/partitionmagic/ps4-controller-buttons.html) (Left shoulder)
D-Pad Up/Down/Left/Right | Sounds | Up=1, Right=2, Down=3, Left=4 (both Up=6) | D-Pad (https://www.partitionwizard.com/partitionmagic/ps4-controller-buttons.html) (Directional pad)
Circle | Sound 9 | Special sound (e.g., whistle) | Circle (https://www.partitionwizard.com/partitionmagic/ps4-controller-buttons.html) (Right face button)
L3 (Left Stick Click) | Dome Servo Mode | Click to toggle servo-follow vs free spin | L3 (https://www.partitionwizard.com/partitionmagic/ps4-controller-buttons.html) (Left stick press)

Dome Controller Visual Mapping (Annotated Diagram): Dome Controller Mappings (https://dribbble.com/shots/3467476/PS4-Controller-Button-Layout) (Imagine annotations: Left Stick = Tilt, L1 = Spin, D-Pad = Sounds, Circle = Special)
Tuning Mode Visuals (Serial Monitor Examples)
During tuning, Serial Monitor shows live values. Pitch Tuning (PS + UP Hold 3 sec):
text
=== PITCH PID TUNING MODE ===
PITCH TUNING | P:78.00→58.50 I:0.00 D:0.00 | ERR P:+8.2 R:+0.1 | OUT
D:+420 S: +3 | ↑↓=±5.0 X=Next ← P
(Screenshot: Serial line with live P value, errors, outputs, and arrow on P) Roll Tuning (PS + RIGHT Hold 3 sec):
text
ROLL TUNING | P:62.00→46.50 I:0.00 D:0.00 | ERR P:+0.1 R:+12.3 | OUT D:
+2 S:+520 | ↑↓=±5.0 X=Next ← P
(Screenshot: Similar line, but roll error dominant, S2S output high)

TECHNICAL DOCUMENTATION (How to Build & Flash)

ESP32 Primary Controller
Overview
This firmware controls the ESP32 Primary Drive System for Joe’s Drive, featuring:
- Side-to-Side (S2S) and Drive Control
- PID Balance with Live Tuning
- Persistent Preferences (no hardcoding)
- ESPNOW Communication with Send Queue
- Diagnostic Telemetry
- Safe Recovery Mode
- Watchdog Protection
- Factory Reset Capability
Features
- Persistent Settings: REVERSE_S2S, REVERSE_DRIVE, ESPNOW, Telemetry, PID gains
- Dynamic ESPNOW Activation: Enable/disable without reboot
- Watchdog Timer: Resets ESP32 if system hangs > 5s
- Safe Recovery: After 3 watchdog resets, disables ESPNOW and debugging
- Auto-Center Calibration: Runs on first boot
- Live PID Tuning: Adjust gains via controller buttons
- Factory Reset: Clears all preferences and reboots
- Version Banner Persistence: Stores version/build info in Preferences

Serial Commands
Use these commands via Serial Monitor or ESPNOW remote:

Wi-Fi & OTA
SET WIFI_SSID <YourSSID> // Set Wi-Fi SSID
SET WIFI_PASS <YourPassword> // Set Wi-Fi password
SET OTA ON|OFF | // Enable or disable OTA updates
SHOW WIFI | // Show current Wi-Fi configuration

Configuration
SET REVERSE_S2S ON|OFF // Reverse Side-to-Side motion
SET REVERSE_DRIVE ON|OFF // Reverse forward/backward drive
SET USE_ESPNOW ON|OFF | // Enable/disable ESPNOW communication
SET TELEMETRY ON|OFF | // Enable diagnostic telemetry
SET ENABLE_ROLL_BIAS ON|OFF // Enable roll bias for S2S return
SET FACTORY_RESET ON // Clear all preferences and reboot

PID Tuning
SET KP <value> | // Pitch PID KP
SET KD <value> | // Pitch PID KD
SET KI <value> | // Pitch PID KI
SET PK2 <value> | // Roll PID Pk2
SET DK2 <value> | // Roll PID Dk2

SET IK2 <value> // Roll PID Ik2

Debug
SET DEBUG_ALL ON|OFF
SET DEBUG_COMPACT ON|OFF
SET DEBUG_CALIBRATION ON|OFF SET DEBUG_JOYSTICK ON|OFF
SET DEBUG_S2S_MODE ON|OFF
SET DEBUG_MOTOR_OUTPUT ON|OFF SET DEBUG_IMU_RAW ON|OFF

Status
SHOW CONFIG | // Displays all current settings
SHOW PID | // Displays current PID gains
SAVE CALIBRATION | // Saves current offsets
RESET CALIBRATION | // Resets offsets to zero
RESET_32U4 | // Sends reset command to secondary board

Drive Controller Shortcuts
- PS + UP (3s) → Start Pitch PID tuning
- PS + RIGHT (3s) → Start Roll PID tuning
- PS + DOWN (3s) → Cancel tuning
- R3 Button → Toggle REVERSE_DRIVE (persists)
- L3 Button → Toggle Dome Servo Mode
- PS Button → Toggle Drive Enable

Both Controller Shortcuts
- UP + UP (3s) → Saves current potOffset, pitchOffset, rollOffset to Preferences
- DOWN + DOWN ( 3s) → Resets offsets to zero

Safe Recovery Mode
- If watchdog resets occur 3 times consecutively, firmware:
- Disables ESPNOW
- Disables telemetry
- Disables all debug flags
- Applies failsafe defaults
- Optional: Factory reset can be triggered manually: SET FACTORY_RESET ON

Watchdog Behavior
- Timeout: 5 seconds

- Feeds: Every loop iteration
- Purpose: Prevent hangs during Serial or ESPNOW operations

Version Banner & Build Info
Stored in Preferences:
Version: JOE'S DRIVE v9.15
Build: <compile date/time>
Displayed at boot:
[BOOT] Version: JOE'S DRIVE v9.15 | Build: Dec 31 2025 12:05:25

OTA Firmware Update Instructions
Arduino IDE
1. Connect ESP32 to Wi-Fi using:
2. SET WIFI_SSID YourSSID
3. SET WIFI_PASS YourPassword
4. SET OTA ON
5. Reboot or confirm OTA is active ([OTA] Ready for updates in Serial Monitor).
6. In Arduino IDE:
- Go to Tools → Port → Network Ports.
- Select your ESP32 device (it will show its IP).
7. Upload your sketch normally. OTA will handle the update wirelessly.

PlatformIO
1. Enable OTA in firmware as above.
2. Find your ESP32 IP (shown in Serial Monitor).
3. In platformio.ini:
INI
upload_protocol = espota
upload_port = <ESP32_IP>
upload_flags =
--auth=securepassword
4. Run:
pio run --target upload

Troubleshooting
- ESPNOW not working?
- Check SHOW CONFIG → USE_ESPNOW=ON
- If fails repeatedly, Safe Recovery may have disabled it
- System keeps rebooting?
- Watchdog may be triggering → Check [BOOT] Reset Reason
- Factory Reset
- Use SET FACTORY_RESET ON → Clears all preferences and reboots
- PID feels unstable?
- Use live tuning mode via controller or SET KP/KD/KI Future Enhancements
- OTA updates for remote firmware flashing
- Advanced failsafe (disable drive motors if IMU lost)
- Persistent debug flags across reboots

Quick Startup Checklist
1. Flash firmware
2. Open Serial Monitor @ 115200
3. Verify version banner and build info
4. Run SHOW CONFIG to confirm settings
5. Adjust preferences via SET commands as needed

Do you want me to also prepare a visual flowchart for Safe Recovery and Boot Logic (showing watchdog detection → failsafe → factory reset)? Or a diagram for ESPNOW + Serial command flow?

Wiring Diagram (ESP32 Motors + Pot)

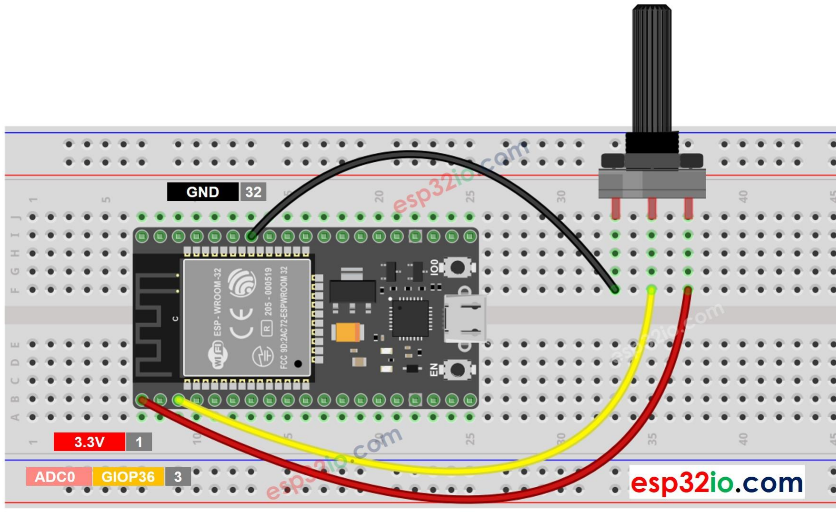
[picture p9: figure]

esp32io.com (https://esp32io.com/tutorials/esp32-potentiometer)
ESP32 - Potentiometer | ESP32 Tutorial
Wiring Diagram (BB-8 Dome Controller)

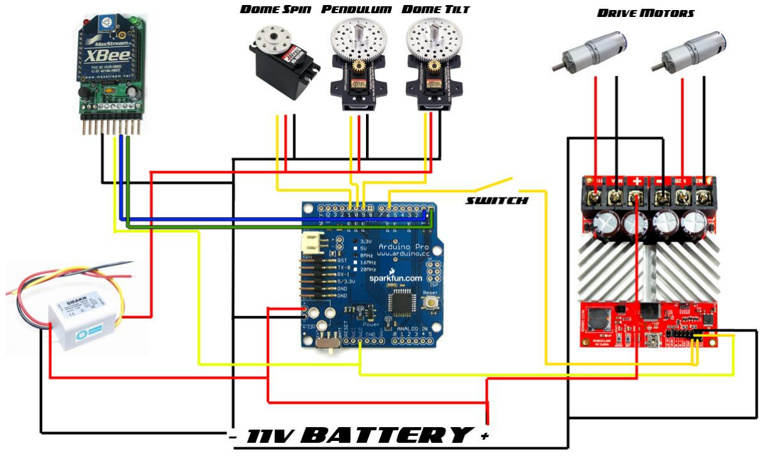
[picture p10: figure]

edsjunk.net (http://www.edsjunk.net/wordpress/bb-8-electronics-guide/)
BB-8 Electronics Guide |
Flashing Code (Arduino IDE)
1. Open Arduino IDE, load sketch.
2. Select board (ESP32 Dev Module for ESP32, Arduino Leonardo for 32u4).
3. Upload. Screenshot:

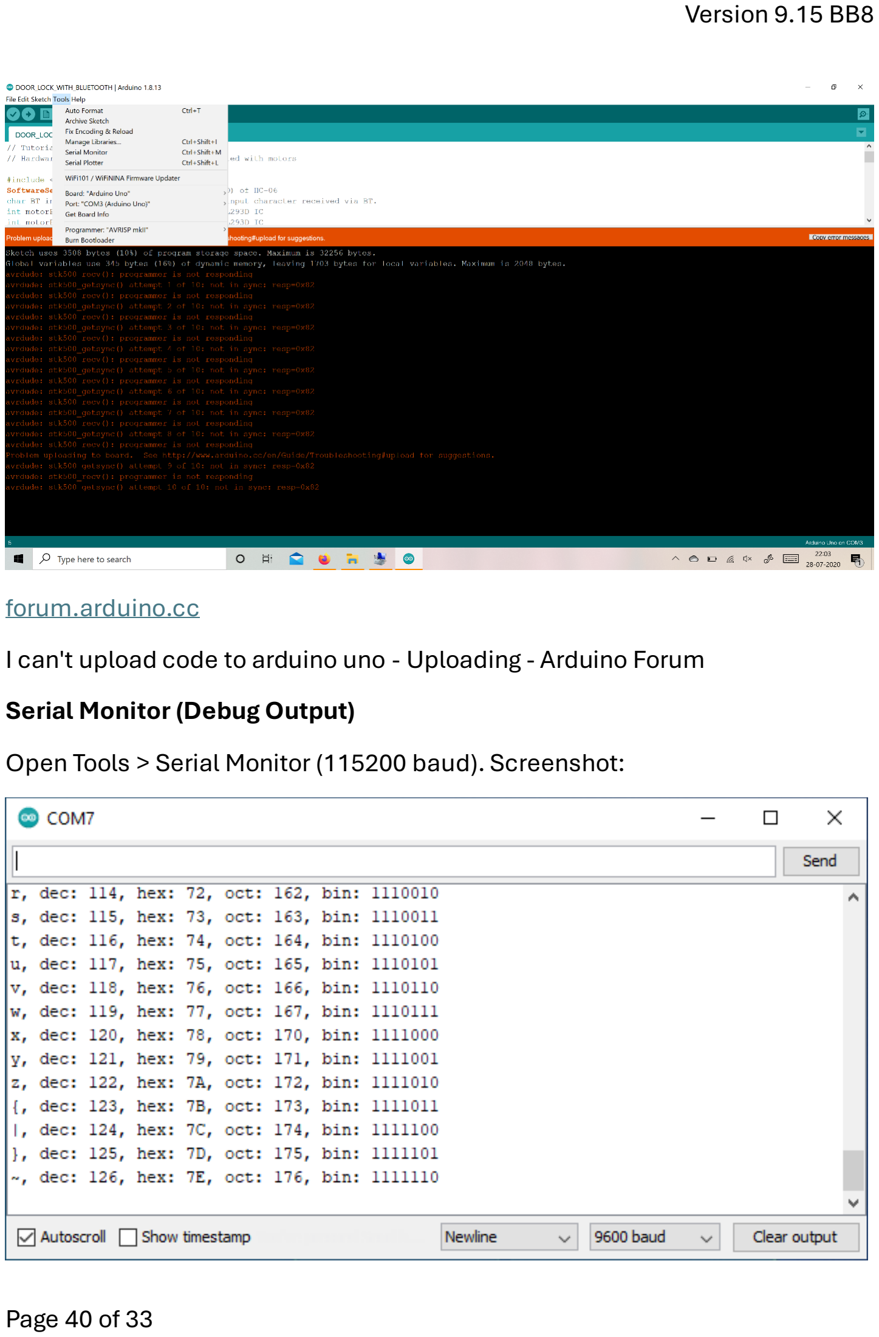
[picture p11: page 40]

forum.arduino.cc (https://forum.arduino.cc/t/i-cant-upload-code-to-arduino-uno/667690)
I can't upload code to arduino uno - Uploading - Arduino Forum Serial Monitor (Debug Output)
Open Tools > Serial Monitor (115200 baud). Screenshot:

startingelectronics.org (https://startingelectronics.org/beginners/arduino-tutorial-for-beginners/arduino-serial-monitor-for-beginners/)
Arduino Serial Monitor for Beginners | Starting Electronics

POT and IMU Calibration Intelligence
Every time you calibrate:
- Center is saved
- Range auto-adjusts to ±400 around your actual center
- No more hardcoding 1300–2150 and using the default 1708
(where the potentiometer is positioned initially with the gantry at level and its stem has the slot horizontal to indicate close to center of its positioning - best guess).
Works perfectly no matter how your pot is mounted so the above is no longer needed.

Main Drive and S2S - PID Tuning
You only have two PIDs to tune — and they are completely independent:
PID | What it controls | Which gains you actually change
Pitch PID (forward/back balance) | Main drive motors when stick is near center | KP_PITCH, KI_PITCH, KD_PITCH
Roll PID (side-to-side balance) | S2S motor when auto-balance is ON | Pk2, Ik2, Dk2 (inside S2S_Movement())

Below is the exact, field-proven method that every builder (including the very best BB8 uses. Do it in this order — never skip steps.

Step 1 – Pitch PID (Drive Balance) – Do this FIRST
This is the most important one. Get this perfect before touching roll.
1. Set I and D to zero first
C++
const float KP_PITCH = 45.0; | // start here
const float KI_PITCH = 0.0; | // ← zero
const float KD_PITCH = 0.0; | // ← zero
2. Increase KP_PITCH only until the droid oscillates
- Stand the droid upright on a flat surface.
- Turn Auto-Balance ON (Cross button).
- Slowly raise KP until it starts rocking forward/back quickly.
- Then back it down ~20–30 % → this is your final KP.
- Example: if it starts oscillating at 70 → set KP_PITCH = 48–55.
3. Add KD_PITCH to stop the oscillation

- With KP set, it will still rock a little.
- Slowly raise KD_PITCH until the rocking damps out quickly and smoothly.
- Typical good value: 8 → 18 (start at 12.0 like v8.7).
4. Add a tiny bit of KI_PITCH to remove the last steady-state lean
- After a few seconds upright, you might still lean a few degrees.
- Add KI very slowly (0.1 → 0.9). Too much KI = slow hunting/oscillation.
- Most builders end up between 0.5 – 1.2. v8.7’s 0.8 is nearly perfect for most.
Final good pitch numbers (real-world examples):

const float KP_PITCH = 48.0;

const float KI_PITCH = 0.80;

const float KD_PITCH = 12.0;

Step 2 – Roll PID (S2S Balance) – Do this SECOND Only tune this after pitch is perfect.
double Pk2 = 45.0; | // Proportional
double Ik2 = 1.0; | // Integral
double Dk2 = 15.0; | // Derivative
Same exact process:
1. Set Ik2 and Dk2 to zero first
2. Raise Pk2 until it oscillates left/right
- Typical oscillation starts around 70–90.
- Back it down 20–30 % → Pk2 ≈ 45–60.
3. Add Dk2 to damp the oscillation
- Usually 12–20 works great. v8.7’s 15.0 is spot-on for most.
4. Add a small Ik2 to remove any steady lean
- 0.8 – 2.0 is normal. 1.0 is almost always perfect.

Final good roll numbers (real-world examples):

double Pk2 = 48.0;

double Ik2 = 1.0;

double Dk2 = 15.0;

FULLY CONTROLLER-BASED LIVE TUNING SYSTEM for BB-8
This firmware supports zero laptop, zero wires, zero guesswork… REALTIME System Settings
These adjust and persist PID gains for Pitch (Drive) and Roll (S2S): SET KP <value> → Set Pitch KP (e.g., SET KP 50)
SET KD <value> → Set Pitch KD (e.g., SET KD 12)
SET KI <value> → Set Pitch KI (e.g., SET KI 0.8)

SET PK2 <value> → Set Roll Pk2 (e.g., SET PK2 45) SET DK2 <value> → Set Roll Dk2 (e.g., SET DK2 15) SET IK2 <value> → Set Roll Ik2 (e.g., SET IK2 1.0)

Via Serial show current PID values: SHOW PID

Via Serial debug Toggles
Enable or disable debug streams live: SET DEBUG_ALL ON/OFF
SET DEBUG_COMPACT ON/OFF
SET DEBUG_CALIBRATION ON/OFF SET DEBUG_JOYSTICK ON/OFF
SET DEBUG_S2S_MODE ON/OFF
SET DEBUG_MOTOR_OUTPUT ON/OFF SET DEBUG_IMU_RAW ON/OFF
Example:
SET DEBUG_COMPACT ON
SET DEBUG_ALL OFF

Feature Toggles
Control runtime features:
SET ENABLE_ESPNOW ON/OFF → Enable ESPNOW remote monitoring SET REVERSE_S2S ON/OFF → Reverse S2S direction
SET ENABLE_ROLL_BIAS ON/OFF → Enable roll bias compensation

Show All Current Settings

Print all active configuration values: SHOW CONFIG
Example output:
[CONFIG]
ENABLE_ESPNOW=OFF
REVERSE_S2S=ON
DEBUG_ALL=ON
DEBUG_COMPACT=OFF
KP=45.00 KD=12.00 KI=0.80
Pk2=45.00 Dk2=15.00 Ik2=1.00

Optional: Save/Reset Calibration SAVE CALIBRATION
RESET CALIBRATION

QUICK START – 90-SECOND PERFECT BALANCE
1. Power on your BB-8
2. Pair your drive controller (the one with the right stick)
3. Hold PS + UP for 3 seconds → PITCH TUNING begins
4. Hold PS + RIGHT for 3 seconds → ROLL TUNING begins
5. Use ↑ ↓ to adjust, X to lock & proceed
6. When finished → normal driving resumes instantly That’s it. Your droid is now perfectly balanced forever.

FULL STEP-BY-STEP TUNING GUIDE WITH REAL SERIAL SCREENSHOTS
STEP 0 – Normal Running (before tuning)
With IMUDEBUG defined
Serial output

JOE'S DRIVE v8.9b — ESP32 MASTER — SERIAL1 IMU + I2C DOME CONTROLLER — READY

T: 12345 INFO: Loaded Cal - Pot:1845 Pitch:-0.12 Roll:+0.08
STEP 1 – Enter PITCH Tuning Mode
Hold PS + UP (↑ ) on the drive controller for 3 seconds
Serial output

=== PITCH PID TUNING MODE ===

PITCH TUNING | P:45.00→33.75 | I:0.00 | D:0.00 | | | ERR P:+12.3 R:+0.1 | | | OUT D:+520 S: +8 | | | X=Next
STEP 2 – Tune Proportional (KP) – Make it oscillate!
Press (↑ UP or ↓ DOWN) repeatedly until the body rocks forward/back quickly ↑ = INCREASE ↓ = DECREASE
Serial output
PITCH TUNING | P:78.00→58.50 | I:0.00 | D:0.00 | | | ERR P:+8.2 R:+0.0 | | | OUT D:+420 S: +3 | | | X=Next
Press X → auto 25% reduction applied
Serial output

KP_PITCH FINAL: 58.50

PITCH TUNING | P:58.50→58.50 | I:0.00 | D:12.00 | | ERR P:+2.1 R:+0.0 | | | OUT D: +98 S: +1 | | | X=Next ← D
STEP 3 – Tune Derivative (KD) – Stop the rocking
Press ↑/↓ until rocking damps out in 1–2 bounces
Serial output
PITCH TUNING | P:58.50→58.50 | I:0.00 | D:18.00 | | ERR P:+0.4 R:+0.0 | | | OUT D: +12 S: +0 | | | X=Next ← D

Press X
Serial output
PITCH TUNING | P:58.50→58.50 | I:0.80 | D:18.00 | | ERR P:+0.1 R:+0.0 | | | OUT D: | +3 S: +0 | | | X=Next ← I
STEP 4 – Tune Integral (KI) – Remove final lean
Add just enough so it settles perfectly upright
Serial output
PITCH TUNING | P:58.50→58.50 | I:1.10 | D:18.00 | | ERR P:+0.0 R:+0.0 | | | OUT D: | +0 S: +0 | | | X=Next ← I
Press X → TUNING COMPLETE
Serial output

=== PID TUNING COMPLETE ===

PITCH: KP=58.50 KI=1.10 KD=18.00

STEP 5 – Enter ROLL Tuning Mode Hold PS + RIGHT for 3 seconds
Serial output

=== ROLL PID TUNING MODE ===

ROLL TUNING | P:45.00→33.75 | I:0.00 | D:0.00 | | | ERR P:+0.1 R:+15.6 | | OUT D: +4 S:+680 | | | X=Next ← P
STEP 6 – Repeat exact same process for Roll (Pk2, Dk2, Ik2)
Final result example:
Serial output
ROLL TUNING | P:62.00→46.50 | I:1.30 | D:17.00 | | ERR P:+0.0 R:+0.0 | | | OUT D: +0 S: +1 | | | X=Next ← I

=== PID TUNING COMPLETE ===

ROLL: Pk2=46.50 Ik2=1.30 Dk2=17.00
WHAT “PERFECT” LOOKS LIKE
Serial output
PITCH TUNING | P:58.50→58.50 | I:1.10 | D:18.00 | | ERR P:+0.0 R:+0.0 | | | OUT D: +0 S: +0 | | | X=Next ← I
ROLL TUNING | | P:46.50→46.50 | I:1.30 | D:17.00 | | ERR P:+0.0 R:+0.0 | | | OUT D: +0 S: +0 | | | X=Next ← I
Zero error. Zero output. Pure stillness.

PRO TIPS FROM THE MASTERS
“2-wheel builders tune their code. Hamster-ball builders tune their weights. Axle-drive builders tune their soul.” — Ancient BB-8 proverb
PID Help based on situation
Situation | Fix
Rocks too fast | Lower P (KP (pitch) or Pk2 (roll))
Rocks slowly (hunting) | Lower I (KI or Ik2)
Overshoots then settles | Raise D (KD or Dk2)
Never quite upright | Raise I slightly
Feels sluggish | Raise P a little

FINAL SERIAL OUTPUT WHEN DONE Serial output

=== PID TUNING COMPLETE ===

PITCH: KP=58.50 KI=1.10 KD=18.00

ROLL: Pk2=46.50 Ik2=1.30 Dk2=17.00

JOE'S DRIVE v8.9b — READY
You just tuned the smoothest BB-8 on Earth using only a controller. No laptop. No wires. No guesswork.

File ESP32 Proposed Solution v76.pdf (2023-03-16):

# Joe’s Drive v2

# The Solution consists of 3 PCB boards

1. Main Board – this regulates power from a single 48v - 12v battery to 5v, 6v or 9v outputs, it has all the necessary connectors to quickly wire to DFRobot H Bridge motor controllers and all required sensors. It utilizes 2 CPUs which segregate duties between dome or main body related motors and sensors
(Feather 32u4 Proto M0 or 32u4 Basic Proto | Feather 32u4 RF Series AND Feather ESP32 HUZZAH Series processors).

NOTE: There are 6 options given depending upon secondary 32u4 and which MP3 trigger you wish to use

2. IMU/MPU Board – this connects via Serial and consists of dedicated CPU (trinket m0) as well as MPU6050 series that regulates Pitch, Tilt and yaw movement on the system.
3. Dome board – this communicates via ESP32NOW to the Main Board and controls LEDs in the dome only. Future adaption of motion sensor and distance sensors.

# Version 7.1/7.5/7.6

# OPTION 1: 32u4 PROTO M0 and i2C MP3 Trigger

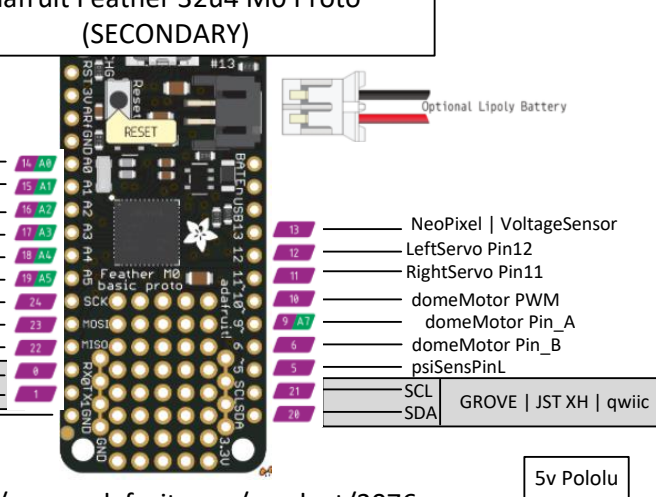
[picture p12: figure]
NeoPixel | VoltageSensor; domeMotor Pin_B; domeMotor Pin_A; psiSensPinL; LeftServo Pin12 RightServo Pin11 domeMotor PWM; SCL; SDA; GROVE | JST XH | qwiic; 5v Pololu; (SECONDARY)
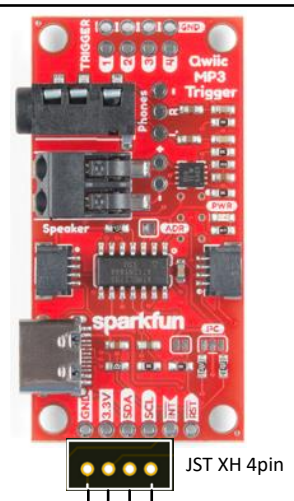
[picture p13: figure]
JST XH 4pin
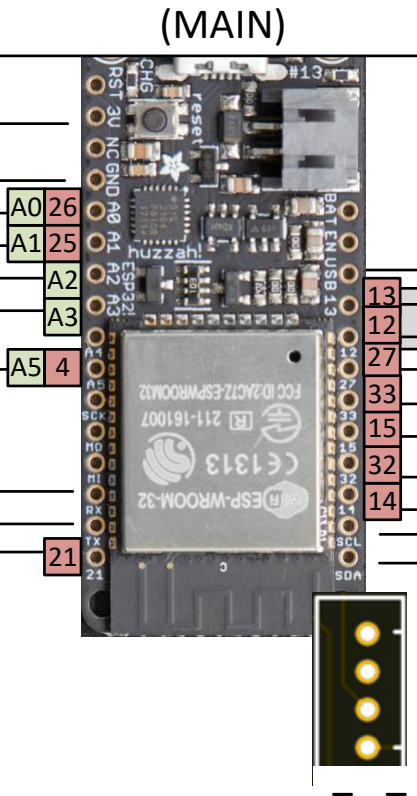
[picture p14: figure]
(MAIN)

S2SPOT

drivepin1

S2SPin1

drivepin2

S2SPin2

Trinket
(Serial1)

To 32u4
(Serial2)

MotorEncPinA
MotorEncPinB

VCCSensor

HallMonitor

To ESP32
(Serial1)

ESP32
(Serial1)

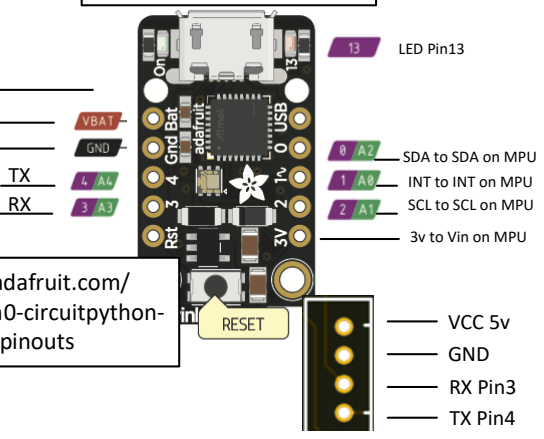
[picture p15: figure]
SCL to SCL on MPU; SDA to SDA on MPU; INT to INT on MPU; 3v to Vin on MPU; TX Pin4; RX Pin3; GND; VCC 5v; LED Pin13

TX

## MPU6050

## Adafruit Trinket M0

5V

GND

SCL

SDA

5v

https://learn.adafruit.com/mpu6050-6-dof-accelerometer-and-gyro/pinouts

https://learn.adafruit.com/adafruit-trinket-m0-circuitpython-arduino/pinouts

GND

INT

i2C

12/24/48v In
5v Out

GND Out
GND In

Bat on 32u4,
Trinket and
ESP32
And Outputs

S2S_PWM

Drive_PWM

GND

+ 3.3v

+5v Input

## https://www.adafruit.com/product/3076

lLogicPIN

battPin (26)
psiPIN (25)

(Serial1)

sLogicPIN

GND

## Adafruit ESP32 HUZZAH32 Feather (DOME)

FlyMotor PWM
FlyMotor Pin_A
FlyMotor Pin_B
SCL
SDA
GND

GND 3.3V SDA SCL
To Feather 32u4

Sparkfun QWIIC MP3 TRIGGER

VCC 5v

GND

TX Pin17 ESP32

RX Pin16 ESP32

## To Trinket (MPU)

## To ESP32 (MAIN)

12/24/48v In
9v/6v Out

GND Out
GND In

To Left/Right
Servo and
Output

6v/9v Pololu

## Adafruit ESP32 HUZZAH32 Feather

## Adafruit Feather 32u4 M0 Proto

# OPTION 2: 32u4 Basic Proto and i2C MP3 Trigger

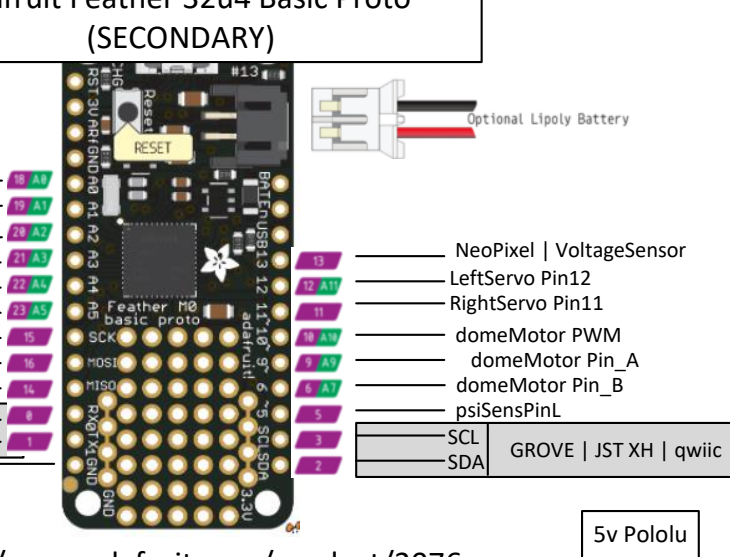
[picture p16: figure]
NeoPixel | VoltageSensor; domeMotor Pin_B; domeMotor Pin_A; psiSensPinL; LeftServo Pin12 RightServo Pin11 domeMotor PWM; SCL; SDA; GROVE | JST XH | qwiic; 5v Pololu; (SECONDARY)

S2SPOT

drivepin1

S2SPin1

drivepin2

S2SPin2

Trinket
(Serial1)

To 32u4
(Serial2)

MotorEncPinA
MotorEncPinB

VCCSensor

HallMonitor

To ESP32
(Serial1)

ESP32
(Serial1)

TX

## MPU6050

## Adafruit Trinket M0

5V

GND

SCL

SDA

5v

https://learn.adafruit.com/mpu6050-6-dof-accelerometer-and-gyro/pinouts

https://learn.adafruit.com/adafruit-trinket-m0-circuitpython-arduino/pinouts

GND

INT

i2C

12/24/48v In
5v Out

GND Out
GND In

Bat on 32u4,
Trinket and
ESP32
And Outputs

S2S_PWM

Drive_PWM

GND

+ 3.3v

+5v Input

## https://www.adafruit.com/product/3076

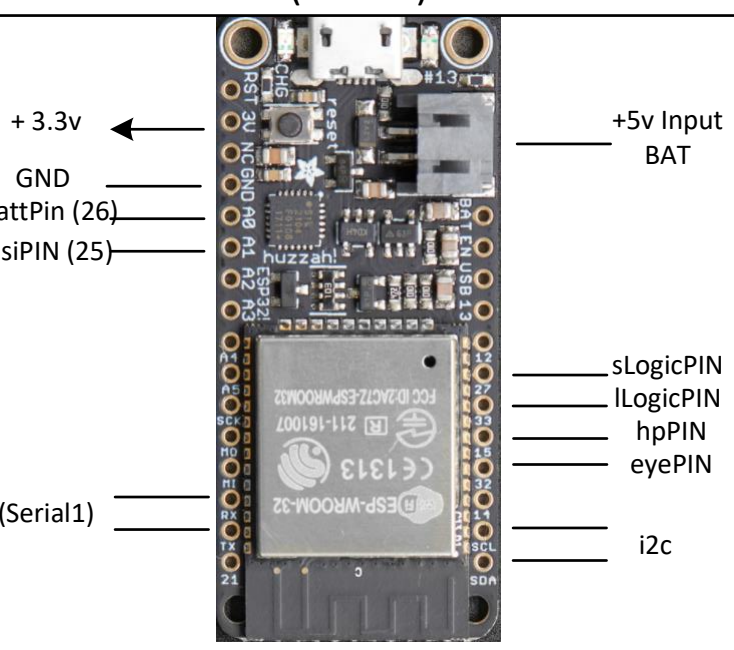
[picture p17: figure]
+5v Input; BAT; hpPIN eyePIN

lLogicPIN

battPin (26)
psiPIN (25)

(Serial1)

sLogicPIN

GND

## Adafruit ESP32 HUZZAH32 Feather (DOME)

FlyMotor PWM
FlyMotor Pin_A
FlyMotor Pin_B
SCL
SDA
GND

GND 3.3V SDA SCL
To Feather 32u4

Sparkfun QWIIC MP3 TRIGGER

VCC 5v

GND

TX Pin17 ESP32

RX Pin16 ESP32

## To Trinket (MPU)

## To ESP32 (MAIN)

12/24/48v In
9v/6v Out

GND Out
GND In

To Left/Right
Servo and
Output

6v/9v Pololu

## Adafruit ESP32 HUZZAH32 Feather

## Adafruit Feather 32u4 Basic Proto

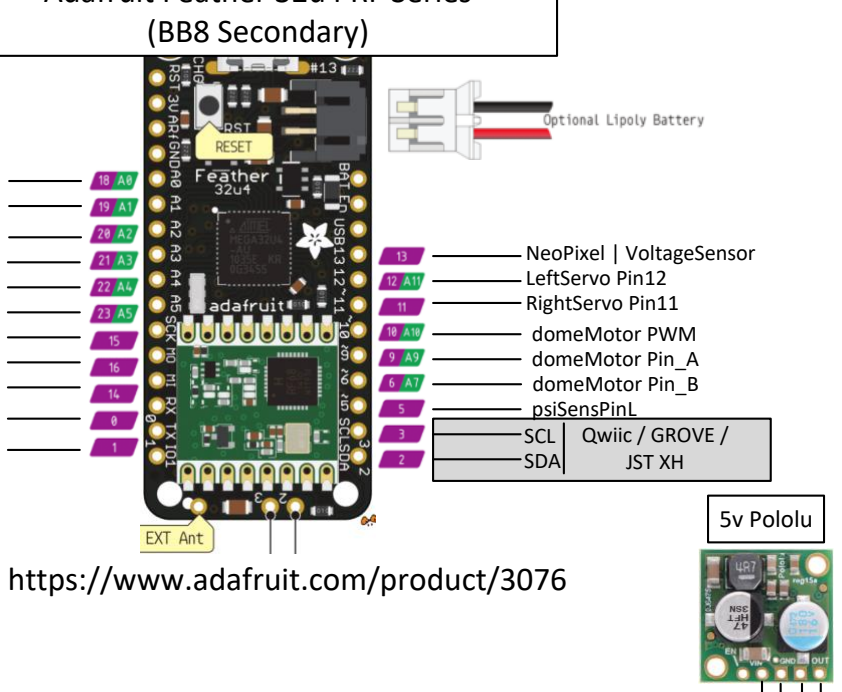
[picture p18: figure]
NeoPixel | VoltageSensor; domeMotor Pin_B; domeMotor Pin_A; psiSensPinL; LeftServo Pin12 RightServo Pin11 domeMotor PWM; https://www.adafruit.com/product/3076; SCL SDA; Qwiic / GROVE / JST XH; 5v Pololu; (BB8 Secondary)

MotorEncPinA
MotorEncPinB
HallMonitor

ESP32
(Serial1)

# OPTION 3: 32u4 RF and i2C MP3 Trigger

S2SPOT

drivepin1

S2SPin1

drivepin2

S2SPin2

Trinket
(Serial1)

To 32u4
(Serial2)

ESP32
(Serial1)

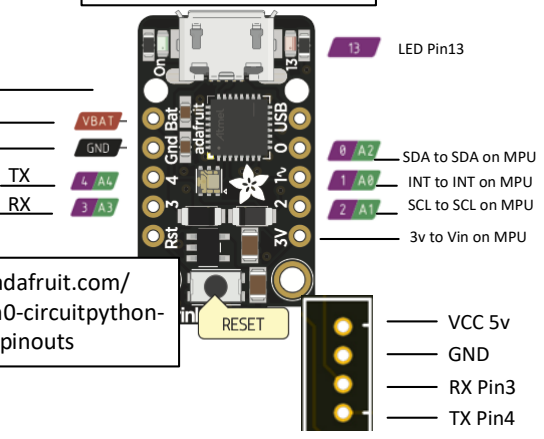
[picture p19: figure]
SCL to SCL on MPU; SDA to SDA on MPU; INT to INT on MPU; 3v to Vin on MPU; TX Pin4; RX Pin3; GND; VCC 5v; LED Pin13

TX

## MPU6050

## Adafruit Trinket M0

5V

GND

SCL

SDA

5v

https://learn.adafruit.com/mpu6050-6-dof-accelerometer-and-gyro/pinouts

https://learn.adafruit.com/adafruit-trinket-m0-circuitpython-arduino/pinouts

GND

INT

i2C

12/24/48v In
5v Out

GND Out
GND In

Bat on 32u4,
Trinket and
ESP32
And Outputs

S2S_PWM

Drive_PWM

GND

+ 3.3v

+5v Input

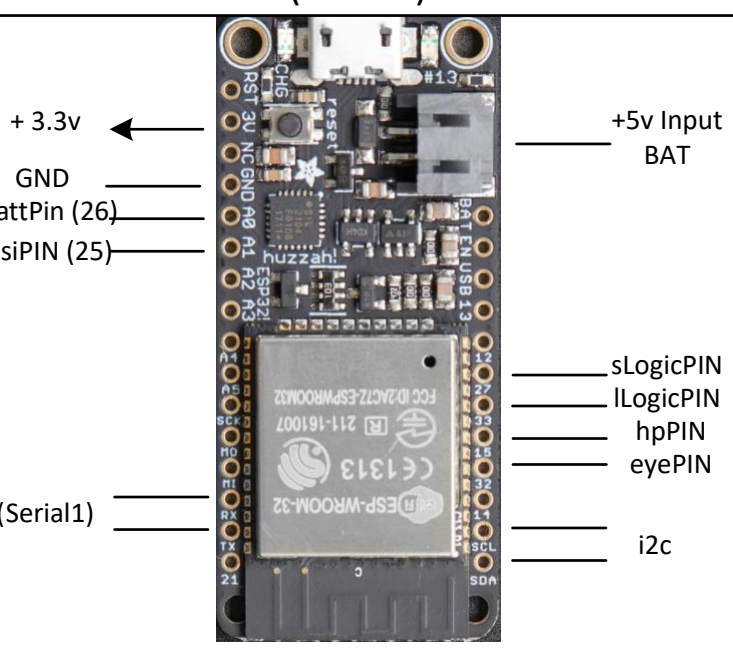
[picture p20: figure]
+5v Input; BAT; hpPIN eyePIN

lLogicPIN

battPin (26)
psiPIN (25)

(Serial1)

sLogicPIN

GND

## Adafruit ESP32 HUZZAH32 Feather (DOME)

FlyMotor PWM
FlyMotor Pin_A
FlyMotor Pin_B
SCL
SDA
GND 3.3V SDA SCL
To Feather 32u4

Sparkfun QWIIC MP3 TRIGGER

VCC 5v

GND

TX Pin17 ESP32

RX Pin16 ESP32

## To Trinket (MPU)

## To ESP32 (MAIN)

12/24/48v In
9v/6v Out

GND Out
GND In

To Left/Right
Servo and
Output

6v/9v Pololu

## Adafruit ESP32 HUZZAH32 Feather Adafruit Feather 32u4 RF Series

# OPTION 4: 32u4 PROTO M0 and ADAFRUIT MUSIC MAKER FEATHERWING

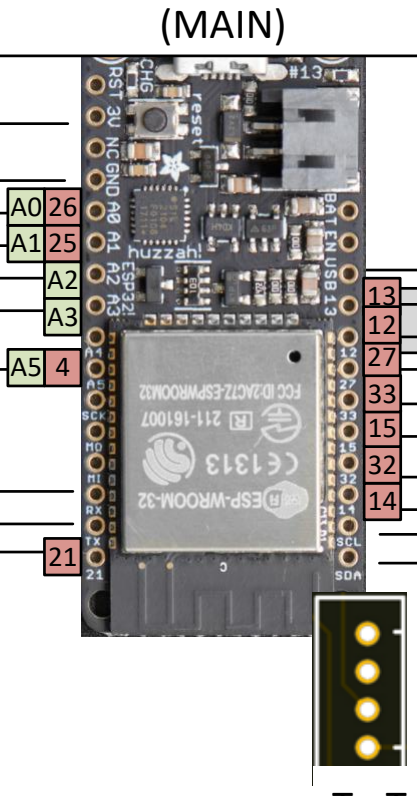
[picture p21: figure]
(MAIN)

S2SPOT

drivepin1

S2SPin1

drivepin2

S2SPin2

Trinket
(Serial1)

To 32u4
(Serial2)

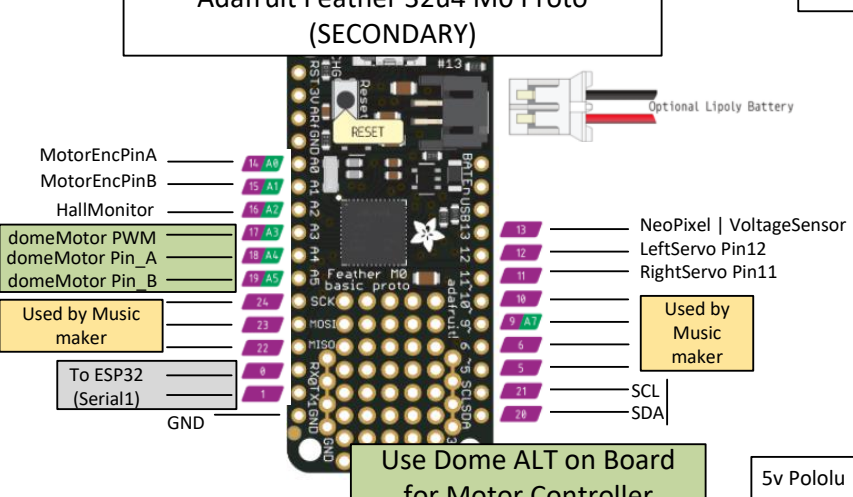
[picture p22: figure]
NeoPixel | VoltageSensor; domeMotor Pin_A; LeftServo Pin12; RightServo Pin11; To ESP32 (Serial1); SCL SDA; GND; 5v Pololu; (SECONDARY); domeMotor PWM; Use Dome ALT on Board; Used by Music maker

MotorEncPinA
MotorEncPinB

domeMotor Pin_B

HallMonitor

ESP32
(Serial1)

TX

## MPU6050

## Adafruit Trinket M0

5V

GND

SCL

SDA

5v

https://learn.adafruit.com/mpu6050-6-dof-accelerometer-and-gyro/pinouts

https://learn.adafruit.com/adafruit-trinket-m0-circuitpython-arduino/pinouts

GND

INT

i2C

12/24/48v In
5v Out

GND Out
GND In

Bat on 32u4,
Trinket and
ESP32
And Outputs

S2S_PWM

Drive_PWM

GND

+ 3.3v

+5v Input

lLogicPIN

battPin (26)
psiPIN (25)

(Serial1)

sLogicPIN

GND

## Adafruit ESP32 HUZZAH32 Feather (DOME)

FlyMotor PWM
FlyMotor Pin_A
FlyMotor Pin_B
SCL
SDA

ADAFRUIT VS105 Feather

VCC 5v

GND

TX Pin17 ESP32

RX Pin16 ESP32

## To Trinket (MPU)

## To ESP32 (MAIN)

12/24/48v In
9v/6v Out

GND Out
GND In

To Left/Right
Servo and
Output

6v/9v Pololu

## Adafruit ESP32 HUZZAH32 Feather

## Adafruit Feather 32u4 M0 Proto

## for Motor Controller

X
X
X

X
X
X
X

# OPTION 5: 32u4 Basic Proto and ADAFRUIT MUSIC MAKER FEATHERWING

S2SPOT

drivepin1

S2SPin1

drivepin2

S2SPin2

Trinket
(Serial1)

To 32u4
(Serial2)

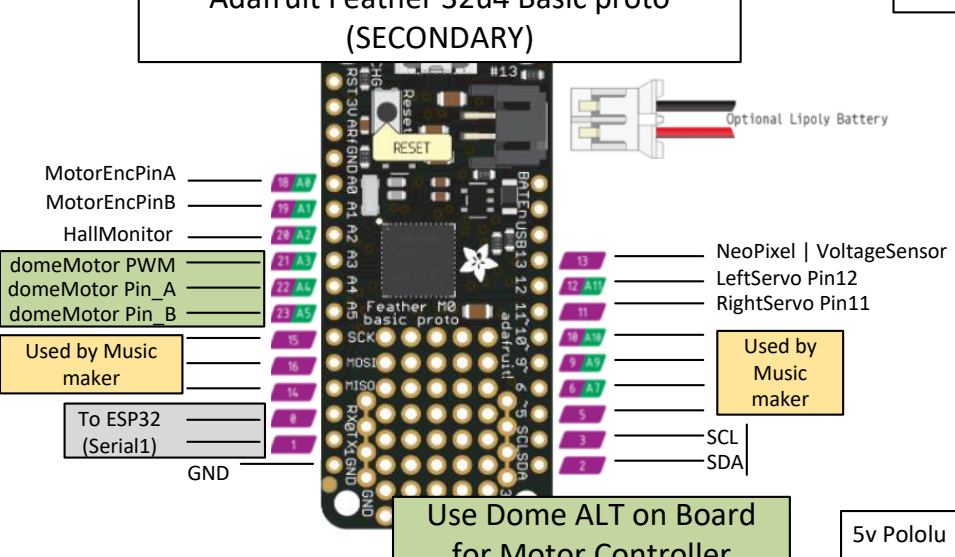
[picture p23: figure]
NeoPixel | VoltageSensor; domeMotor Pin_A; LeftServo Pin12; RightServo Pin11; To ESP32 (Serial1); SCL SDA; GND; 5v Pololu; (SECONDARY); domeMotor PWM; Use Dome ALT on Board; Used by Music maker

MotorEncPinA
MotorEncPinB

domeMotor Pin_B

HallMonitor

ESP32
(Serial1)

TX

## MPU6050

## Adafruit Trinket M0

5V

GND

SCL

SDA

5v

https://learn.adafruit.com/mpu6050-6-dof-accelerometer-and-gyro/pinouts

https://learn.adafruit.com/adafruit-trinket-m0-circuitpython-arduino/pinouts

GND

INT

i2C

12/24/48v In
5v Out

GND Out
GND In

Bat on 32u4,
Trinket and
ESP32
And Outputs

S2S_PWM

Drive_PWM

GND

+ 3.3v

+5v Input

lLogicPIN

battPin (26)
psiPIN (25)

(Serial1)

sLogicPIN

GND

## Adafruit ESP32 HUZZAH32 Feather (DOME)

FlyMotor PWM
FlyMotor Pin_A
FlyMotor Pin_B
SCL
SDA

ADAFRUIT VS105 Feather

VCC 5v

GND

TX Pin17 ESP32

RX Pin16 ESP32

## To Trinket (MPU)

## To ESP32 (MAIN)

12/24/48v In
9v/6v Out

GND Out
GND In

To Left/Right
Servo and
Output

6v/9v Pololu

## Adafruit ESP32 HUZZAH32 Feather

## Adafruit Feather 32u4 Basic proto

## for Motor Controller

X
X
X

X
X
X
X

# OPTION 6: 32u4 Basic Proto and i2C MP3 Trigger from Zio

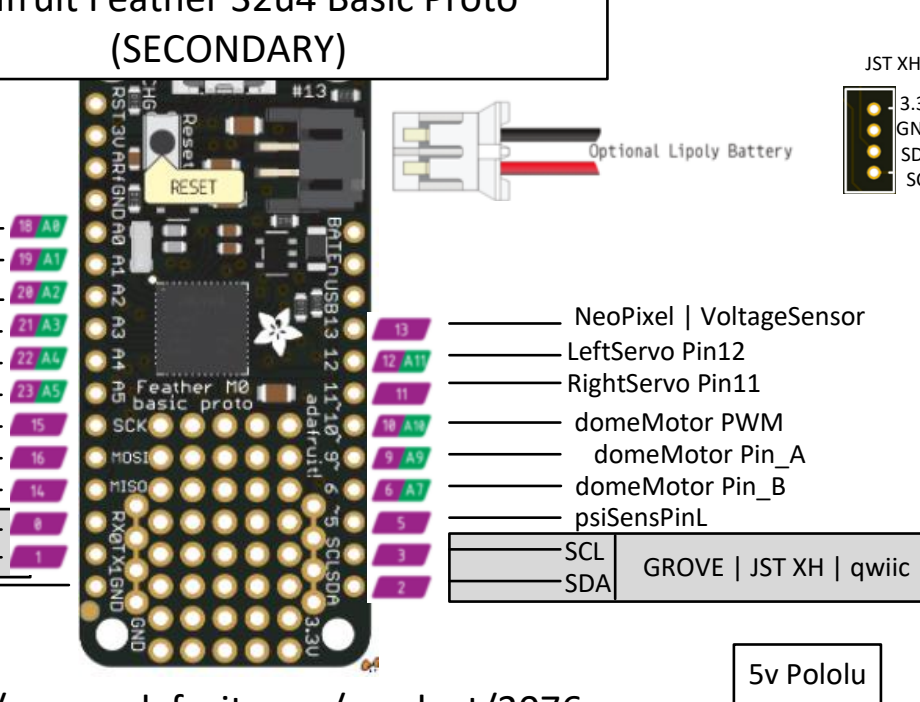
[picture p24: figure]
NeoPixel | VoltageSensor; domeMotor Pin_B; domeMotor Pin_A; psiSensPinL; LeftServo Pin12 RightServo Pin11 domeMotor PWM; SCL; SDA; GROVE | JST XH | qwiic; 5v Pololu; (SECONDARY)

S2SPOT

drivepin1

S2SPin1

drivepin2

S2SPin2

Trinket
(Serial1)

To 32u4
(Serial2)

MotorEncPinA
MotorEncPinB

VCCSensor

HallMonitor

To ESP32
(Serial1)

ESP32
(Serial1)

TX

## MPU6050

## Adafruit Trinket M0

5V

GND

SCL

SDA

5v

https://learn.adafruit.com/mpu6050-6-dof-accelerometer-and-gyro/pinouts

https://learn.adafruit.com/adafruit-trinket-m0-circuitpython-arduino/pinouts

GND

INT

i2C

12/24/48v In
5v Out

GND Out
GND In

Bat on 32u4,
Trinket and
ESP32
And Outputs

S2S_PWM

Drive_PWM

GND

+ 3.3v

+5v Input

## https://www.adafruit.com/product/3076

lLogicPIN

battPin (26)
psiPIN (25)

(Serial1)

sLogicPIN

GND

## Adafruit ESP32 HUZZAH32 Feather (DOME)

FlyMotor PWM
FlyMotor Pin_A
FlyMotor Pin_B
SCL
SDA
GND

3.3v
GND
SDA
SCL

JST XH 4pin

To Feather 32u4

Zio QWIIC MP3 TRIGGER

VCC 5v

GND

TX Pin17 ESP32

RX Pin16 ESP32

## To Trinket (MPU)

## To ESP32 (MAIN)

12/24/48v In
9v/6v Out

GND Out
GND In

To Left/Right
Servo and
Output

6v/9v Pololu

## Adafruit ESP32 HUZZAH32 Feather

## Adafruit Feather 32u4 Basic Proto

Qwiic to
GROVE
Connector

## MOTOR DRIVER 1

## MOTOR DRIVER 2

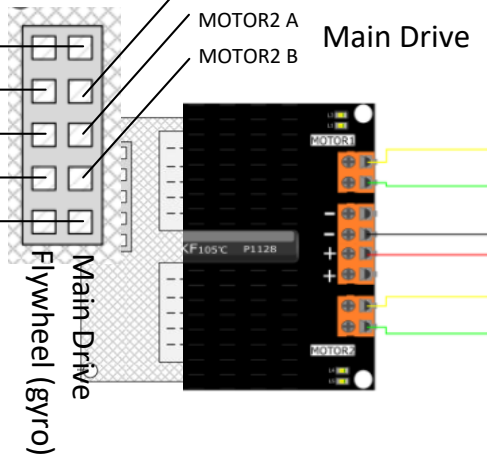
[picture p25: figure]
MOTOR2 A; MOTOR2 B; Main Drive; Flywheel (gyro)

VCC 3.3v

GND

VCC 3.3v

GND

## S2S Motor

## Flywheel (gyro)

## Main Drive

## VCC 12/24v

## VCC 12/24v

MOTOR1 A

MOTOR1 B

## Flywheel (gyro)

MOTOR1 A

MOTOR1 B

## Head Spin

MOTOR1 PWM

MOTOR2 PWM

MOTOR1 PWM

MOTOR2 PWM

#define S2S_pwm 33 // SCL 22 and SDA 23 #define S2S_pin_1 26 //A0

#define S2S_pin_2 25 //A1

#define Drive_pwm 21 // SCL 22 and SDA 23 #define Drive_pin_1 4

#define Drive_pin_2 27

#define domeMotor_pwm 21

#define domeMotor_pin_A 22 #define domeMotor_pin_B 23

ALT w/ MUSIC MAKER FEATHERWING #define domeMotor_pwm A3
#define domeMotor_pin_A A4 #define domeMotor_pin_B A5

#define flyWheelMotor_pwm 15 #define flyWheelMotor_pin_A 32 #define flyWheelMotor_pin_B 14

32u4

## ESP32

## ESP32

## ESP32

## DOME Motor

## To Trinket (MPU)

GND TX
Pin17
ESP32

RX
Pin16
ESP32

VCC 24v to Buck Convertors

GND

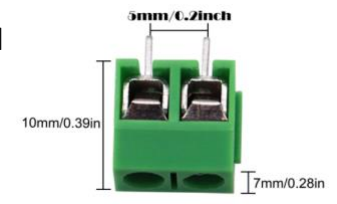
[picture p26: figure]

## Screw Terminal INPUT

## S2S Motor

PinA0
ESP32

PinA1
ESP32

## Drive Motor

Pin4
ESP32

Pin21
ESP32

## S2S POT

VCC
3.3v

PinA2
ESP32

## NEOPIX

VCC
5v Buck

Pin27
ESP32 GND

VCC 5v from Buck Convertors

GND

## Screw Terminal 5v Output

VCC 6v from Buck Convertors

GND

## Screw Terminal 6v Output

## To DomeSpin

VCC
5v GND
Pin3
32u4

Pin2
32u4

## Future

Pin5
32u4

Pin21
32u4

Pin22
ESP32
SCL

Pin23
ESP32
SDA

## Gyro / Fly

Pin9
32u4

Pin6
32u4

## Dome Motor

Pin10
32u4

Pin13
32u4

## Right Servo

Pin 11
32u4 | VCC
| 9v
| From
| Buck

GND

## Left Servo

Pin 12
32u4 | VCC
| 9v
| From
| Buck

GND

## PSI Sensor

Pin20
32u4

Pin18
32u4

## Hall Sensor

Pin 19
32u4

GND

VCC
3.3v

GND

## VCC Sensor

Pin22
32u4 GND

https://www.amazon.com/
s?k=2+Pin+%26+3+Pin+5mm%2F0. 2inch+Pitch+PCB+Mount&i=industr ial&ref=nb_sb_noss

## JST-XH 2.54mm

## i2c ESP32

GND
ESP32
GND
Motor Driver 1 | Motor Driver 2

VCC
32U4
3.3V

GND
GND

Pin21
32u4

Pin22
32u4

Pin23
32u4

Pin15
ESP32

VCC
Esp32
3.3V

Pin32
ESP32

Pin14
ESP32

VCC
5v

## Drive

## GYRO

S2S

## Dome 1

1

VCC 9v from Buck Convertors

GND

## Screw Terminal 9v Output

RX TX

## Serial Debug

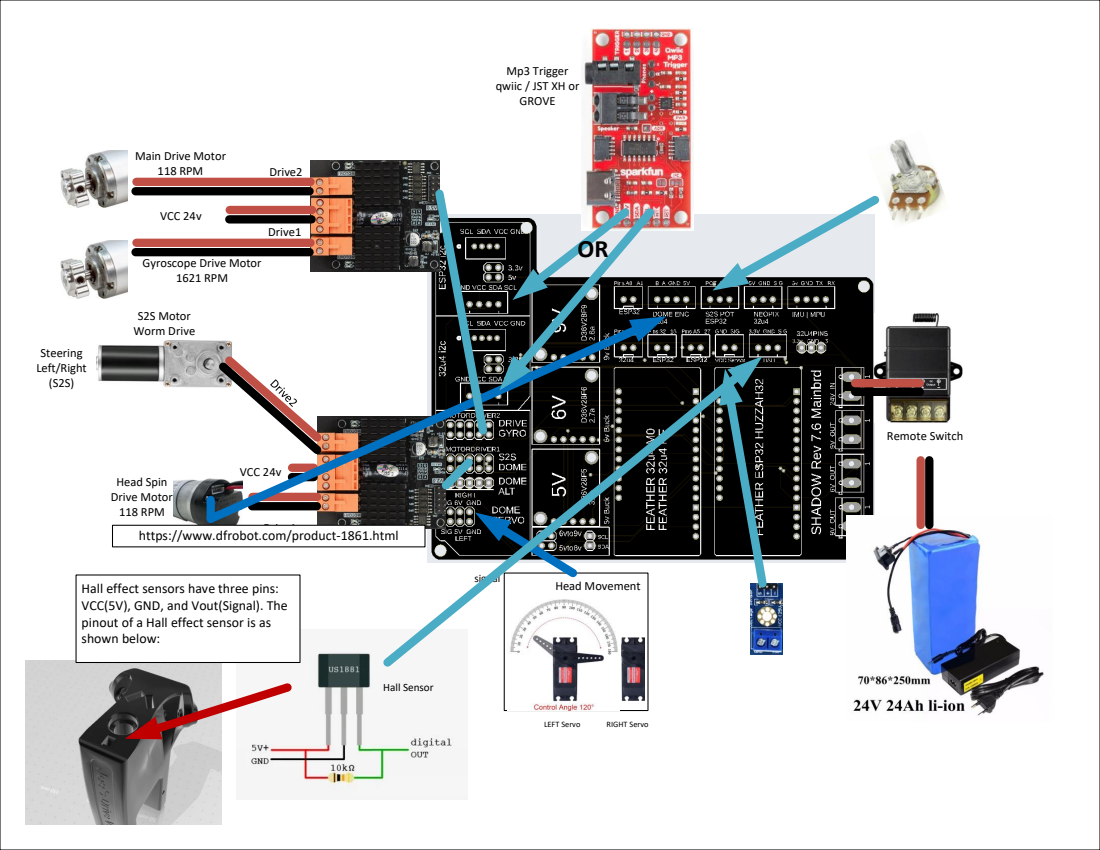
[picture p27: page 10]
Head Movement; Remote Switch; LEFT Servo; RIGHT Servo; S2S Motor Worm Drive; Drive1; Drive2; Steering Left/Right (S2S); signal; VCC 24v; Hall Sensor

Mp3 Trigger
qwiic / JST XH or
GROVE

Main Drive Motor
118 RPM

Gyroscope Drive Motor
1621 RPM

Head Spin
Drive Motor
https://www.dfrobot.com/product-1861.html

Hall effect sensors have three pins:
VCC(5V), GND, and Vout(Signal). The
pinout of a Hall effect sensor is as
shown below:

# MAIN BOARD 7.1/7.5

## StepDowns

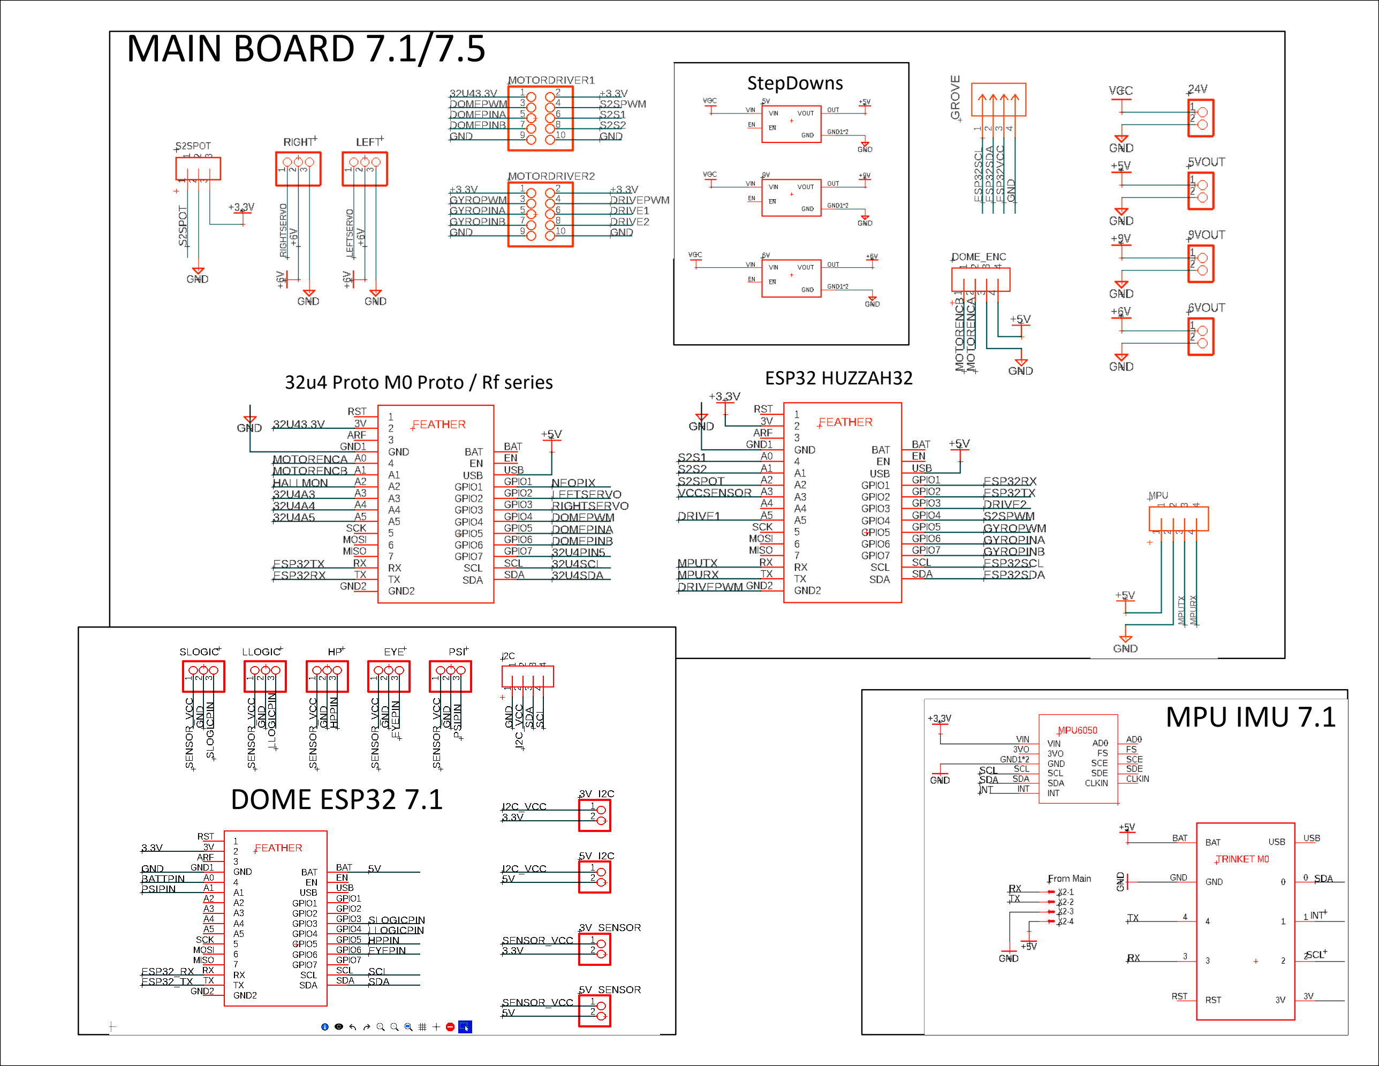
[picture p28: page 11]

# MPU IMU 7.1

# DOME ESP32 7.1

32u4 Proto M0 Proto / Rf series | ESP32 HUZZAH32

+5v Input; BAT; hpPIN eyePIN

lLogicPIN

battPin (26)
psiPIN (25)

eyeLED Single

(Serial1)

sLogicPIN

GND

## Adafruit ESP32 HUZZAH Feather (BB8 Dome)

HP (hpPIN)
Holo
Single

psiPIN (25)
PSILED
Single

eyePIN

sLogicPIN
sLOGIC
3 lights

lLogic
6 lights

18mm

80mm

Sensor:; MPU6050_A; Type:; Acceleration (m/s2); Driver Ver: 1 Unique ID: 1617 Min Value: -156.91 Max Value: 156.91 Resolution: 0.06 ------------------------------------; MPU6050_G; Gyroscopic (rad/s); Driver Ver: 1 Unique ID: 1618 Min Value: -34.91 Max Value: 34.91 Resolution: 0.00 ------------------------------------

IMU BOARD with TRINKET as CPU

80mm

# IMU BOARD with ProMicro as CPU

i2C via; qwiic

# MAIN BOARD Revision 7.1


# IMU/MPU Board(s)

# Dome Board

# Main Board

## Important Changes:

## - Focused on i2c with grove and jst-xh connectors for the ESP32

# MAIN BOARD Revision 7.5


# IMU/MPU Board(s)

# Dome Board

# Main Board

## Important Changes:

## - Reversed position of the 2 Feathers to allow clearance for the Serial ports - Added ALT position for Dome Motor to allow for

Featherwing (MP3) on secondary feather.

## - Changed the Dome Servos to 2x3 pin header for

easier soldering and space saving.

# MAIN BOARD Revision 7.6


# IMU/MPU Board(s)

# Dome Board

# Main Board

## Important Changes:

## - Added 2nd GROVE for 32u4 supported MP3 - Added 2x2pin headers to ease soldering for: - I2c VCCs - BUCK VCCs

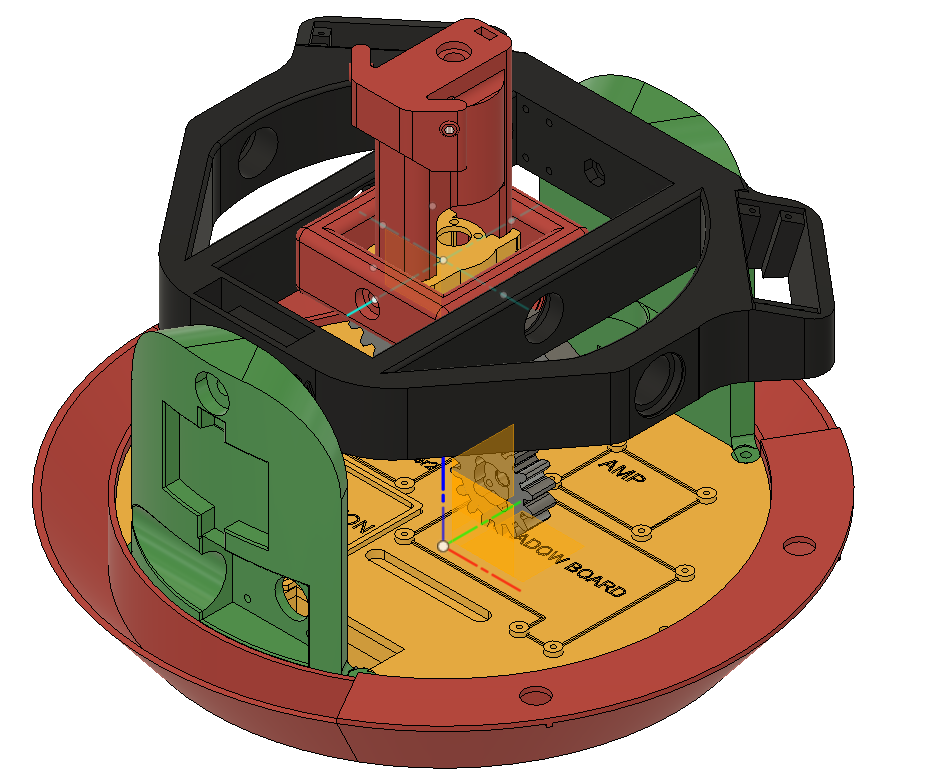
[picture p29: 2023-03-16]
Z-Class System v2.png

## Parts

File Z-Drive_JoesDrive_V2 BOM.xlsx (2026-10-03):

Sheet: Sheet 1
BOM
Part | Total needed | Purchase | Cost per | Cost total | URL | Total: |  | $1243.33
ADAFRUIT
Adafruit Feather 32u4 RFM69HCW Packet Radio - 868 or 915 MHz - RadioFruit | 1 | 1 | $24.95 | $24.95 | https://www.adafruit.com/product/5000 |  | https://www.adafruit
Or you can Purchase Adafruit Feather Proto M0 | 1 | 1 | $19.95 | $19.95 | https://www.adafruit.com/product/2771
Hall effect Sensor | 1 | 1 | $2.00 | $2.00 | https://www.adafruit.com (https://www.adafruit.com/product/158) |  | https://www.adafruit
Assembled Adafruit HUZZAH32 – ESP32 Feather Board - with Stacking Headers | 2 | 2 | $21.95 | $43.90 | https://www.adafruit.com (https://www.adafruit.com/product/3619) |  | https://www.adafruit
MPU | 1 | 1 | $6.95 | $6.95 | https://www.adafruit.com (https://www.adafruit.com/product/3886) |  | https://www.adafruit
Trinket m0 | 1 | 1 | $8.95 | $8.95 | https://www.adafruit.com (https://www.adafruit.com/product/3500) |  | https://www.adafruit
Header Kit for Feather - 12-pin and 16-pin Female Header Set | 2 | 2 | $0.95 | $1.90 | https://www.adafruit.com/product/2886
NeoPixel Diffused 5mm Through-Hole LED - 5 Pack | 2 | 2 | $4.95 | $9.90 | https://www.adafruit.com/product/1938
NeoPixel Jewel - 7 x 5050 RGB LED with Integrated Drivers | 1 | 1 | $5.95 | $5.95 | https://www.adafruit.com/product/2226
NeoPixel Stick - 8 x 5050 RGBW LEDs - Warm White - ~3000K | 2 | 2 | $7.95 | $15.90 | https://www.adafruit.com/product/2867
 |  |  |  | $140.35
AMAZON
12v Lithium Battery | 1 |  | $112.99 | $0.00 | https://www.amazon.com (https://www.amazon.com/gp/product/B00JK06CK8/ref=ppx_yo_dt_b_search_asin_title?ie=UTF8&psc=1) |  | https://www.amazon.c
12v Stronger Amperage | 1 |  | $60.00 | $0.00 | https://www.ebay.com (https://www.ebay.com/itm/313551938183?hash=item490126e287:g:gzQAAOSwZ6tfSGYj)
24v Lithium Battery (24V 28ah electric bicycle Li-ion battery 500W) | 1 | 1 | $100.00 | $100.00 | https://www.ebay.com (https://www.ebay.com/itm/373419267114?hash=item56f185d42a:g:5cYAAOSwmCxfzxCO)
300MM lazy susan | 1 | 1 | $25.00 | $25.00 | https://www.amazon.com/gp/product/B01L8EHD6K/ref=ppx_yo_dt_b_search_asin_title?ie=UTF8&psc=1 |  | https://www.amazon.c
608zz | 4 | 1 | $9.79 | $9.79 | https://www.amazon.com (https://www.amazon.com/Sackorange-Skateboard-Bearings-Miniature-Bearings%EF%BC%88Pack/dp/B07216D1SZ) |  | https://www.amazon.c
Amp | 1 | 1 | $16.99 | $16.99 | https://www.amazon.com (https://www.amazon.com/gp/product/B01N1UHTU1/ref=ppx_yo_dt_b_search_asin_title?ie=UTF8&psc=1) |  | https://www.amazon.c
power distribution and fuse system | 1 | 1 | $15.99 | $15.99 | SOYOND Waterproof Fuse Block,fuse Box With Led Indicator Damp-proof Cover 12 Circuits With Negative Marine Fuse Block For Dc 12/24v Automotive Car Marine Boat RV Truck https://www.amazon.com/dp/B07HDZVW3P
Fuse block | 1 | 0 | $9.99 | $0.00 | https://www.amazon.com (https://www.amazon.com/WATERWICH-Standard-Circuit-Waterproof-Protection/dp/B07CWNTJL5) |  | https://www.amazon.c
Fuse block 12v 6-way | 1 | 1 | $13.99 | $13.99 | https://www.amazon.com/gp/product/B07HDZVW3P/ref=ppx_yo_dt_b_search_asin_title?ie=UTF8&psc=1 |  | https://www.amazon.c
Micro to A adapter | 1 | 1 | $4.96 | $4.96 | https://www.amazon.com/Rankie-Female-Adapter-Convertor-3-Pack/dp/B00YOX4JU6 |  | https://www.amazon.c
Pot (200k) | 1 | 1 | $7.42 | $7.42 | https://www.amazon.com/Uxcell-a15011600ux0235-Linear-Rotary-Potentiometer/dp/B01DKCUVMQ |  | https://www.amazon.c
Power Remote On/Off Controller | 1 | 1 | $23.00 | $23.00 | https://www.amazon.com/dp/B07P4DZ2JT |  | https://www.amazon.c
Power Switch (Optional) | 1 | 1 | $5.55 | $5.55 | https://www.amazon.com/Gardner-Bender-GSW-10-Electrical-Terminal/dp/B000HOT1CM?pid=Q1gG8Eh&s=industrial |  | https://www.amazon.c
Servos (BB Series) | 2 | 2 | $42.99 | $85.98 | https://www.amazon.com/PDI-HV2060MG-Voltage-Digital-Helicopter-Airplane/dp/B07PSLD9P9 |  | https://www.amazon.c
Slipring | 2 | 2 | $17.71 | $35.42 | https://www.amazon.com/Taidacent-Conductive-Collector-Electrical-Commutator/dp/B07NW9PT4P |  | https://www.amazon.c
Small Buck | 1 | 1 | $11.99 | $11.99 | https://www.amazon.com/gp/product/B07CVBG8CT/ref=ppx_yo_dt_b_search_asin_title?ie=UTF8&psc=1 |  | https://www.amazon.c
Voltage Sensor | 1 | 1 | $5.39 | $5.39 | https://www.amazon.com/HiLetgo-Voltage-Detection-Arduino-Electronic/dp/B01HTC4XKY?s=hi |  | https://www.amazon.c
Worm gear motor (130rpm) (S2S) | 1 | 1 | $26.76 | $26.76 | https://www.amazon.com/gp/product/B08KFX6XG8/ref=ewc_pr_img_1?smid=A2K5DI8VX12AN1&th=1 |  | #REF!
Worm gear motor (65rpm) (S2S) | 1 | 0 | $29.29 | $0.00 | https://www.amazon.com/gp/product/B07KLMM49K/ref=ppx_yo_dt_b_search_asin_title?ie=UTF8&psc=1 |  | https://www.amazon.c
Transducers | 2 | 2 | $24.17 | $48.34 | https://amzn.to/3qkbLBZ
1" 3.5mm headphone cable (right angle) | 1 | 1 | $5.99 | $5.99 | https://amzn.to/3swwPqX
3.5 mm groud loop isolator | 1 | 1 | $11.99 | $11.99 | https://amzn.to/2LSiDrh
Female Pin Headers | 1 | 1 | $5.60 | $5.60 | https://www.amazon.com/dp/B01DLX6RSQ/ref=cm_sw_r_cp_api_glt_fabc_ina53cGbVKJT0JX
15 Sets JST XH 2.54MM 4 PIN Female Single Connector with 300mm Wire 1007 26AWG | 1 | 1 | $8.99 | $8.99 | https://www.amazon.com/2-54MM-Female-Single-Connector-300mm/dp/B01IZAHR5M?s=electronics
20 PCS 3 PIN JST XH Female Connector on One Side - 200mm 1007 26 AWG & 20 PCS 3 PIN JST XH Male Connector | 1 | 1 | $7.99 | $7.99 | https://www.amazon.com/2-54MM-Female-Single-Connector-Wires/dp/B07FBHKY8G?s=electronics
30 PCS 2 PIN JST XH Female Connector on Both Side - 200mm 1007 26 AWG & 60 PCS 2 PIN JST XH Male Connector | 1 | 1 | $7.99 | $7.99 | https://www.amazon.com/LATTECH-Female-Connector-Electric-Length/dp/B07NTY4972?s=electronics
50cm Female to Female dupont | 1 | 1 | $5.00 | $5.00 | Amazon.com: EDGELEC 120pcs 10cm Dupont Wire Female to Female Breadboard Jumper Wires 3.9 inch 1pin-1pin 2.54mm Connector Multicolored Ribbon Cables DIY Wires Length 10 15 20 30 40 50 100cm Optional: Home Audio & Theater (https://www.amazon.com/EDGELEC-Breadboard-1pin-1pin-Connector-Multicolored/dp/B07GCZBH51)
 |  |  |  | $490.12
ANDYMARK
NeveRest Classic 60 Gearmotor | 1 | 1 | $31.50 | $31.50 | https://www.andymark.com/products/neverest-classic-60-gearmotor?quantity=1 |  | https://www.andymark
JST-PH ENC Cable to breakouts | 1 | 1 | $5.00 | $5.00 | https://www.andymark.com/products/hall-effect-encoder-cable-encoder-connector-to-split-end-connector
DF ROBOT
Motor Driver 12A | 2 | 2 | $29.00 | $58.00 | https://www.dfrobot.com/product-1861.html |  | https://www.dfrobot.
DFRDuino Player (i2C) MP3 playerwiki.dfrobot.com/DFRduino_Player__SKU_DFR0112_ | 1 | 1 | $9.00 | $9.00 | DFPlayer Pro MP3 Player Module for Voice Activated System | Arduino / Raspberry Pi - DFRobot (https://www.dfrobot.com/product-2232.html)
DF Payer Mini
MCMASTER CARR
#4 screw x .5” (100pk) | 6 | 1 | $2.40 | $2.40 | https://www.mcmaster.com/90190A108 |  | https://www.mcmaster
#4 screw x .75” (100pk) | 8 | 1 | $2.94 | $2.94 | https://www.mcmaster.com/90190A113 |  | https://www.mcmaster
#4 screw 1/4" long (100pk) | 25 | 1 | $2.19 | $2.19 | https://www.mcmaster.com/90190A106/ |  | https://www.mcmaster
#6 washers (100pk) | 100 | 1 | $1.20 | $1.20 | https://www.mcmaster.com/92141A008 |  | https://www.mcmaster
#10 nuts (100pk) | 2 | 1 | $3.77 | $3.77 | https://www.mcmaster.com/91841A195 |  | https://www.mcmaster
#10 rod ends (RH Thread) | 4 | 4 | $3.77 | $15.08 | https://www.mcmaster.com/60645K31 |  | https://www.mcmaster
#10 threaded rod (will cut to length) | 1 | 1 | $1.14 | $1.14 | https://www.mcmaster.com/90032A048 |  | https://www.mcmaster
#10 x 2” | 1 | 1 | $2.65 | $2.65 | https://www.mcmaster.com/92949A275 |  | https://www.mcmaster
1/4"-20 x 1” (50pk) | 8 | 1 | $8.49 | $8.49 | https://www.mcmaster.com/92949A542 |  | https://www.mcmaster
1/4”-20 x 7/16” (50pk) | 4 | 1 | $6.03 | $6.03 | https://www.mcmaster.com/92949A833 |  | https://www.mcmaster
6-32 x .375” (100pk) | 4 | 1 | $3.72 | $3.72 | https://www.mcmaster.com/92949A146 |  | https://www.mcmaster
6-32 x .5” (100pk) | 4 | 1 | $3.72 | $3.72 | https://www.mcmaster.com/92949A148 |  | https://www.mcmaster
6-32 x .75” (100pk) | 4 | 1 | $4.41 | $4.41 | https://www.mcmaster.com/92949A151 |  | https://www.mcmaster
6-32 x 1” (100pk) | 12 | 1 | $5.42 | $5.42 | https://www.mcmaster.com/92949A153 |  | https://www.mcmaster
10-32 square nuts (100pk) | 8 | 1 | $3.39 | $3.39 | https://www.mcmaster.com/94855A283 |  | https://www.mcmaster
10-32 x 1.25” FH (25pk) | 4 | 1 | $5.02 | $5.02 | https://www.mcmaster.com/91253A012 |  | https://www.mcmaster
10-32 x 2” flat head (10pk) | 6 | 1 | $6.21 | $6.21 | https://www.mcmaster.com/90585A299 |  | https://www.mcmaster
M3 lock nut (100pk) | 4 | 1 | $3.57 | $3.57 | https://www.mcmaster.com/90576A102 |  | https://www.mcmaster
M3 x 10 (100 pk) | 11 | 1 | $8.38 | $8.38 | https://www.mcmaster.com/92095A182 |  | https://www.mcmaster
M3 x 25mm (50pk) | 1 | 1 | $6.13 | $6.13 | https://www.mcmaster.com/92095A186 |  | https://www.mcmaster
M4 nut (100 pk) | 2 | 1 | $1.41 | $1.41 | https://www.mcmaster.com/90592A090 |  | https://www.mcmaster
M4 x 45mm (25pk) | 2 | 1 | $6.81 | $6.81 | https://www.mcmaster.com/92095A205 |  | https://www.mcmaster
M5 flange nut (100pk) | 14 | 1 | $10.02 | $10.02 | https://www.mcmaster.com/97400A858 |  | https://www.mcmaster
M5 x 35mm Flat Head (25pk) | 12 | 1 | $7.22 | $7.22 | https://www.mcmaster.com/92125A222 |  | https://www.mcmaster
M5 x 55 Flat Head (25pk) | 2 | 1 | $9.63 | $9.63 | https://www.mcmaster.com/92125A218 |  | https://www.mcmaster
M8 lock nut (50pk) | 2 | 1 | $7.86 | $7.86 | https://www.mcmaster.com/97131A140 |  | https://www.mcmaster
M8 x 50mm (25pk) | 1 | 1 | $9.14 | $9.14 | https://www.mcmaster.com/91280A546 |  | https://www.mcmaster
M8 x 55mm (25pk) | 1 | 1 | $8.91 | $8.91 | https://www.mcmaster.com/91280A548 |  | https://www.mcmaster
 |  |  |  | $156.86
SERVOCITY
0.375" to 6mm Set Screw Shaft Coupler | 1 | 1 | $4.99 | $4.99 | https://www.servocity.com/0-375-to-6mm-set-screw-shaft-coupler/ |  | https://www.servocit
1” HD Hub | 3 | 3 | $14.99 | $44.97 | https://www.servocity.com/1-bore-face-tapped-heavy-duty-clamping-hub-1-50-pattern/ |  | https://www.servocit
1” ID bearing | 8 | 8 | $9.99 | $79.92 | https://www.servocity.com/1-id-x-1-245-od-flanged-ball-bearing/ |  | https://www.servocit
1” stainless tube cut to 6.75” | 2 | 2 | $8.69 | $17.38 | https://www.servocity.com/1-00-x-8-00-stainless-steel-tubing/ |  | https://www.servocit
118rpm motor (drive) | 1 | 1 | $39.99 | $39.99 | https://www.servocity.com/118-rpm-hd-premium-planetary-gear-motor/ |  | https://www.servocit
1621rpm motor (FlyWheel) | 1 | 1 | $39.99 | $39.99 | https://www.servocity.com/1-621-rpm-hd-premium-planetary-gear-motor/ |  | https://www.servocit
16t sprocket | 1 | 1 | $3.99 | $3.99 | https://www.servocity.com/16-tooth-0-770-aluminum-hub-mount-sprocket-0-250-pitch/ |  | https://www.servocit
3/8" alu, tube | 1 | 1 | $4.09 | $4.09 | https://www.servocity.com/0-375-3-8-x-12-00-aluminum-tubing/ |  | https://www.servocit
3/8" bore clamp | 1 | 1 | $6.99 | $6.99 | https://www.servocity.com/0-375-0-770-clamping-hub/ |  | https://www.servocit
3/8" ID x 5/8" OD Non-Flanged Ball Bearing (2pk) | 4 | 2 | $2.79 | $5.58 | https://www.servocity.com/3-8-id-x-5-8-od-non-flanged-ball-bearing-2-pack/ |  | https://www.servocit
Alternative via Active Robots website (UK) | 2 | 1 | $16.00 | $16.00 | https://www.active-robots.com/1-4-id-x-1-2-od-non-flanged-ball-bearing-2-pack.html
32mm clamp | 4 | 4 | $6.99 | $27.96 | https://www.servocity.com/32mm-bore-bottom-tapped-clamping-mount/ |  | https://www.servocit
40t sprocket | 1 | 1 | $6.39 | $6.39 | https://www.servocity.com/40-tooth-1-50-aluminum-hub-mount-sprockets-0-250-pitch/ |  | https://www.servocit
6mm d hub | 2 | 2 | $6.99 | $13.98 | https://www.servocity.com/1311-series-thru-hole-sonic-hub-6mm-d-bore/ |  | https://www.servocit
8mm hub | 1 | 1 | $5.99 | $5.99 | https://www.servocity.com/1309-series-sonic-hub-8mm-bore/ |  | https://www.servocit
Chain | 1 | 1 | $5.99 | $5.99 | https://www.servocity.com/0-250-chain-5-feet/ |  | https://www.servocit
Chain Tool (breaker) | 1 | 1 | $25.00 | $25.00 | https://www.servocity.com/0-250-pitch-chain-tool/
 |  |  |  | $349.20 |  |  | https://www.servocit
SPARKFUN Electronics
SparkFun Qwiic MP3 Trigger | 0 | 0 | $20.00 | $0.00 | https://www.sparkfun.com/products/19030
 | 1 | 1 | $56.50 | $56.50 | LilyPad MP3 - SparkFun Electronics (https://www.sparkfun.com/lilypad-mp3.html)
Qwiic Cable - Grove Adapter (100mm) | 1 | 1 | $1.50 | $1.50 | https://www.sparkfun.com/products/15109
 |  |  |  | $58.00 |  |  | https://www.servocit
POLOLU Robotics and Electronics
Screw Terminal Block: 2-Pin, 5 mm Pitch | 3 | 1 | $1.50 | $1.50 | https://www.pololu.com/product/2440
5V, 3.2A Step-Down Voltage Regulator D36V28F5 | 1 | 1 | $11.95 | $11.95 | https://www.pololu.com/product/3782
6V, 2.7A Step-Down Voltage Regulator D36V28F6 | 1 | 1 | $11.95 | $11.95 | https://www.pololu.com/product/3783
9V, 2.6A Step-Down Voltage Regulator D36V28F9 | 1 | 1 | $11.95 | $11.95 | https://www.pololu.com/product/3785
(2.54 mm) Female Header: 2x5-Pin, Straight | 1 | 1 | 0.69 | $0.69 | https://www.pololu.com/product/1025
(2.54 mm) Female Header: 1x5-Pin, Straight | 2 | 2 | 0.44 | $0.88 | https://www.pololu.com/product/1015
(2.54 mm) Female Header: 1x5-Pin, Straight | 2 | 2 | 0.44 | $0.88 | https://www.pololu.com/product/1015
 |  |  |  | $39.80
 |  |  | Total Cost: | $1243.33

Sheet: Build Parts
S2SArm
55 x 4mm bolts
5 x 5mm bolts
.5 x small screws
FlyWheelArm

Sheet: Sheet1
ALTERNATE BOM 2025-2027
Part | Total needed | Purchase | Cost per | Cost total | URL
ADAFRUIT
Adafruit Feather 32u4 Basic Proto | 1 | 1 | $19.95 | $19.95 | https://www.adafruit.com/product/2771
Hall effect Sensor | 1 | 1 | $2.00 | $2.00 | https://www.adafruit.com (https://www.adafruit.com/product/158)
Assembled Adafruit HUZZAH32 – ESP32 Feather Board - with Stacking Headers | 2 | 2 | $21.95 | $43.90 | https://www.adafruit.com (https://www.adafruit.com/product/3619)
MPU | 1 | 1 | $6.95 | $6.95 | https://www.adafruit.com (https://www.adafruit.com/product/3886)
Trinket m0 | 1 | 1 | $8.95 | $8.95 | https://www.adafruit.com (https://www.adafruit.com/product/3500)
Header Kit for Feather - 12-pin and 16-pin Female Header Set | 2 | 2 | $0.95 | $1.90 | https://www.adafruit.com/product/2886
NeoPixel Diffused 5mm Through-Hole LED - 5 Pack | 2 | 2 | $4.95 | $9.90 | https://www.adafruit.com/product/1938
NeoPixel Jewel - 7 x 5050 RGB LED with Integrated Drivers | 1 | 1 | $5.95 | $5.95 | https://www.adafruit.com/product/2226
NeoPixel Stick - 8 x 5050 RGBW LEDs - Warm White - ~3000K | 2 | 2 | $7.95 | $15.90 | https://www.adafruit.com/product/2867
 |  |  |  | $115.40
AMAZON
12v Lithium Battery | 1 |  | $112.99 | $0.00 | https://www.amazon.com (https://www.amazon.com/gp/product/B00JK06CK8/ref=ppx_yo_dt_b_search_asin_title?ie=UTF8&psc=1)
12v Stronger Amperage | 1 |  | $60.00 | $0.00 | https://www.ebay.com (https://www.ebay.com/itm/313551938183?hash=item490126e287:g:gzQAAOSwZ6tfSGYj)
24v Lithium Battery (24V 28ah electric bicycle Li-ion battery 500W) | 1 | 1 | $100.00 | $100.00 | https://www.ebay.com (https://www.ebay.com/itm/373419267114?hash=item56f185d42a:g:5cYAAOSwmCxfzxCO)
300MM lazy susan | 1 | 1 | $25.00 | $25.00 | https://www.amazon.com/gp/product/B01L8EHD6K/ref=ppx_yo_dt_b_search_asin_title?ie=UTF8&psc=1
608zz | 4 | 1 | $9.79 | $9.79 | https://www.amazon.com (https://www.amazon.com/Sackorange-Skateboard-Bearings-Miniature-Bearings%EF%BC%88Pack/dp/B07216D1SZ)
Amp | 1 | 1 | $16.99 | $16.99 | https://www.amazon.com (https://www.amazon.com/gp/product/B01N1UHTU1/ref=ppx_yo_dt_b_search_asin_title?ie=UTF8&psc=1)
power distribution and fuse system | 1 | 1 | $15.99 | $15.99 | SOYOND Waterproof Fuse Block,fuse Box With Led Indicator Damp-proof Cover 12 Circuits With Negative Marine Fuse Block For Dc 12/24v Automotive Car Marine Boat RV Truck https://www.amazon.com/dp/B07HDZVW3P
Fuse block | 1 | 0 | $9.99 | $0.00 | https://www.amazon.com (https://www.amazon.com/WATERWICH-Standard-Circuit-Waterproof-Protection/dp/B07CWNTJL5)
Fuse block 12v 6-way | 1 | 1 | $13.99 | $13.99 | https://www.amazon.com/gp/product/B07HDZVW3P/ref=ppx_yo_dt_b_search_asin_title?ie=UTF8&psc=1
Micro to A adapter | 1 | 1 | $4.96 | $4.96 | https://www.amazon.com/Rankie-Female-Adapter-Convertor-3-Pack/dp/B00YOX4JU6
Pot (200k) | 1 | 1 | $7.42 | $7.42 | https://www.amazon.com/Uxcell-a15011600ux0235-Linear-Rotary-Potentiometer/dp/B01DKCUVMQ
Power Remote On/Off Controller | 1 | 1 | $23.00 | $23.00 | https://www.amazon.com/dp/B07P4DZ2JT
Power Switch (Optional) | 1 | 1 | $5.55 | $5.55 | https://www.amazon.com/Gardner-Bender-GSW-10-Electrical-Terminal/dp/B000HOT1CM?pid=Q1gG8Eh&s=industrial
Servos (BB Series) | 2 | 2 | $42.99 | $85.98 | https://www.aliexpress.us/item/3256803586373345.html?src=bing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 (https://www.amazon.com/PDI-HV2060MG-Voltage-Digital-Helicopter-Airplane/dp/B07PSLD9P9)
Stepdown 5v | 1 | 1 | $10.00 | $10.00 | https://www.amazon.com/dp/B00J3MHRNO?ref_=ppx_hzsearch_conn_dt_b_fed_asin_title_7&th=1
Stepdown 6v | 1 | 1 | $16.00 | $16.00 | Amazon.com: DC-DC 6V 10A 60W Step-Down Converter 12V 24V to 6V Power Transformer Converter with Fuse, Waterproof Voltage Regulator… : Electronics (https://www.amazon.com/dp/B0CPQ78W91?ref_=ppx_hzsearch_conn_dt_b_fed_asin_title_3&th=1)
Worm gear motor (130rpm) (S2S) | 1 | 1 | $26.76 | $26.76 | https://www.amazon.com/gp/product/B08KFX6XG8/ref=ewc_pr_img_1?smid=A2K5DI8VX12AN1&th=1
Speakers | 1 | 1 | $24.17 | $24.17 | https://www.amazon.com/dp/B081169PC5?ref=ppx_yo2ov_dt_b_fed_asin_title
Amplifier | 1 | 1 | $10.00 | $10.00 | Amazon.com: 2PCS TDA2050 DC 12-24V 5W-120W Mono Amplifier One Channel Mono Audio Amplifier Board Power Amplifier Board Module Mono Amplifier : Industrial & Scientific (https://www.amazon.com/dp/B0DMFC6D2G?ref=ppx_yo2ov_dt_b_fed_asin_title)
Female Pin Headers | 1 | 1 | $5.60 | $5.60 | https://www.amazon.com/dp/B01DLX6RSQ/ref=cm_sw_r_cp_api_glt_fabc_ina53cGbVKJT0JX
15 Sets JST XH 2.54MM 4 PIN Female Single Connector with 300mm Wire 1007 26AWG | 1 | 1 | $8.99 | $8.99 | https://www.amazon.com/2-54MM-Female-Single-Connector-300mm/dp/B01IZAHR5M?s=electronics
20 PCS 3 PIN JST XH Female Connector on One Side - 200mm 1007 26 AWG & 20 PCS 3 PIN JST XH Male Connector | 1 | 1 | $7.99 | $7.99 | https://www.amazon.com/2-54MM-Female-Single-Connector-Wires/dp/B07FBHKY8G?s=electronics
30 PCS 2 PIN JST XH Female Connector on Both Side - 200mm 1007 26 AWG & 60 PCS 2 PIN JST XH Male Connector | 1 | 1 | $7.99 | $7.99 | https://www.amazon.com/LATTECH-Female-Connector-Electric-Length/dp/B07NTY4972?s=electronics
50cm Female to Female dupont | 1 | 1 | $5.00 | $5.00 | Amazon.com: EDGELEC 120pcs 10cm Dupont Wire Female to Female Breadboard Jumper Wires 3.9 inch 1pin-1pin 2.54mm Connector Multicolored Ribbon Cables DIY Wires Length 10 15 20 30 40 50 100cm Optional: Home Audio & Theater (https://www.amazon.com/EDGELEC-Breadboard-1pin-1pin-Connector-Multicolored/dp/B07GCZBH51)
 |  |  |  | $431.17
ANDYMARK
NeveRest Classic 60 Gearmotor | 1 | 1 | $31.50 | $31.50 | https://www.andymark.com/products/neverest-classic-60-gearmotor?quantity=1
JST-PH ENC Cable to breakouts | 1 | 1 | $5.00 | $5.00 | https://www.andymark.com/products/hall-effect-encoder-cable-encoder-connector-to-split-end-connector
DF ROBOT
Motor Driver 12A | 2 | 2 | $29.00 | $58.00 | https://www.dfrobot.com/product-1861.html
DF Payer Mini | 1 | 1 | $6.00 | $6.00 | DFPlayer Mini MP3 Player for Arduino Best-selling Audio Module - DFRobot (https://www.dfrobot.com/product-1121.html)
MCMASTER CARR
#4 screw x .5” (100pk) | 6 | 1 | $2.40 | $2.40 | https://www.mcmaster.com/90190A108
#4 screw x .75” (100pk) | 8 | 1 | $2.94 | $2.94 | https://www.mcmaster.com/90190A113
#4 screw 1/4" long (100pk) | 25 | 1 | $2.19 | $2.19 | https://www.mcmaster.com/90190A106/
#6 washers (100pk) | 100 | 1 | $1.20 | $1.20 | https://www.mcmaster.com/92141A008
#10 nuts (100pk) | 2 | 1 | $3.77 | $3.77 | https://www.mcmaster.com/91841A195
#10 rod ends (RH Thread) | 4 | 4 | $3.77 | $15.08 | https://www.mcmaster.com/60645K31
#10 threaded rod (will cut to length) | 1 | 1 | $1.14 | $1.14 | https://www.mcmaster.com/90032A048
#10 x 2” | 1 | 1 | $2.65 | $2.65 | https://www.mcmaster.com/92949A275
1/4"-20 x 1” (50pk) | 8 | 1 | $8.49 | $8.49 | https://www.mcmaster.com/92949A542
1/4”-20 x 7/16” (50pk) | 4 | 1 | $6.03 | $6.03 | https://www.mcmaster.com/92949A833
6-32 x .375” (100pk) | 4 | 1 | $3.72 | $3.72 | https://www.mcmaster.com/92949A146
6-32 x .5” (100pk) | 4 | 1 | $3.72 | $3.72 | https://www.mcmaster.com/92949A148
6-32 x .75” (100pk) | 4 | 1 | $4.41 | $4.41 | https://www.mcmaster.com/92949A151
6-32 x 1” (100pk) | 12 | 1 | $5.42 | $5.42 | https://www.mcmaster.com/92949A153
10-32 square nuts (100pk) | 8 | 1 | $3.39 | $3.39 | https://www.mcmaster.com/94855A283
10-32 x 1.25” FH (25pk) | 4 | 1 | $5.02 | $5.02 | https://www.mcmaster.com/91253A012
10-32 x 2” flat head (10pk) | 6 | 1 | $6.21 | $6.21 | https://www.mcmaster.com/90585A299
M3 lock nut (100pk) | 4 | 1 | $3.57 | $3.57 | https://www.mcmaster.com/90576A102
M3 x 10 (100 pk) | 11 | 1 | $8.38 | $8.38 | https://www.mcmaster.com/92095A182
M3 x 25mm (50pk) | 1 | 1 | $6.13 | $6.13 | https://www.mcmaster.com/92095A186
M4 nut (100 pk) | 2 | 1 | $1.41 | $1.41 | https://www.mcmaster.com/90592A090
M4 x 45mm (25pk) | 2 | 1 | $6.81 | $6.81 | https://www.mcmaster.com/92095A205
M5 flange nut (100pk) | 14 | 1 | $10.02 | $10.02 | https://www.mcmaster.com/97400A858
M5 x 35mm Flat Head (25pk) | 12 | 1 | $7.22 | $7.22 | https://www.mcmaster.com/92125A222
M5 x 55 Flat Head (25pk) | 2 | 1 | $9.63 | $9.63 | https://www.mcmaster.com/92125A218
M8 lock nut (50pk) | 2 | 1 | $7.86 | $7.86 | https://www.mcmaster.com/97131A140
M8 x 50mm (25pk) | 1 | 1 | $9.14 | $9.14 | https://www.mcmaster.com/91280A546
M8 x 55mm (25pk) | 1 | 1 | $8.91 | $8.91 | https://www.mcmaster.com/91280A548
 |  |  |  | $156.86
SERVOCITY
1” ID bearing | 8 | 8 | $9.99 | $79.92 | https://www.servocity.com/1-id-x-1-245-od-flanged-ball-bearing/
1” stainless tube cut to 6.75” | 2 | 2 | $8.69 | $17.38 | https://www.servocity.com/1-00-x-8-00-stainless-steel-tubing/
118rpm motor (drive) | 1 | 1 | $39.99 | $39.99 | https://www.servocity.com/118-rpm-hd-premium-planetary-gear-motor/
1621rpm motor (FlyWheel) | 1 | 1 | $39.99 | $39.99 | https://www.servocity.com/1-621-rpm-hd-premium-planetary-gear-motor/
SPROCKET/CHAIN
3307 Series 8mm Pitch Steel Set-Screw Sprocket | 1 | 1 | $9.99 | $9.99 | https://www.servocity.com/3307-series-8mm-pitch-steel-set-screw-sprocket-6mm-d-bore-10-tooth/
Chain 3309 Series 8mm Pitch Plastic Chain | 1 | 1 | $7.99 | $7.99 | https://www.servocity.com/3309-series-8mm-pitch-plastic-chain-50-links-400mm-black/
Main Drive sprocket 32mm Bore, 42 Tooth | 1 | 1 | $12.99 | $12.99 | https://www.servocity.com/3310-series-8mm-pitch-aluminum-hub-mount-sprocket-32mm-bore-42-tooth/
1” HD Hub 1302 | 1 | 1 | $14.99 | $14.99 | https://www.servocity.com/1302-series-clamping-hub-1-bore/
Chain Tool (breaker) | 1 | 1 | 25 | 25 | https://www.servocity.com/0-250-pitch-chain-tool/
PLASTIC MESH GEARING
1” HD Hub 1302 | 1 | 1 | $14.99 | $14.99 | https://www.servocity.com/1302-series-clamping-hub-1-bore/
HEAD TILT ASSEMBLY
0.375" to 6mm Set Screw Shaft Coupler | 0 | 0 | $4.99 | $0.00 | https://www.servocity.com/0-375-to-6mm-set-screw-shaft-coupler/
3/8" alu, tube (9.525mm) | 1 | 1 | $4.09 | $4.09 | https://www.servocity.com/0-375-3-8-x-12-00-aluminum-tubing/
3/8" bore clamp | 1 | 1 | $6.99 | $6.99 | https://www.servocity.com/0-375-0-770-clamping-hub/
3/8" ID x 5/8" OD Non-Flanged Ball Bearing (2pk) | 4 | 2 | $2.79 | $5.58 | https://www.servocity.com/3-8-id-x-5-8-od-non-flanged-ball-bearing-2-pack/
DRIVE / S2S and GYRO CONNECTIONS
23mm Bore Clamb Drive Motor Mount | 4 | 4 | $8.99 | $35.96 | 1400 Series 1-Side, 2-Post Clamping Mount (32mm Bore) - ServoCity® (https://www.servocity.com/1400-series-1-side-2-post-clamping-mount-32mm-bore/)
6mm d hub | 2 | 2 | $6.99 | $13.98 | https://www.servocity.com/1311-series-thru-hole-sonic-hub-6mm-d-bore/
8mm hub | 1 | 1 | 5.99 | 5.99 | https://www.servocity.com/1309-series-sonic-hub-8mm-bore/
SPARKFUN
Logic Level Shifter for v9.x boards | 1 | 1 | 5.99 | 5.99 | SparkFun Logic Level Converter - Bi-Directional | Step down 5V signals to 3.3V AND steps up 3.3V to 5V Board Dimensions: 0.63 x 0.52" (16.05 x 13.33mm): Amazon.com: Industrial & Scientific (https://www.amazon.com/dp/B088FYQJYZ?ref_=ppx_hzsearch_conn_dt_b_fed_asin_title_6)

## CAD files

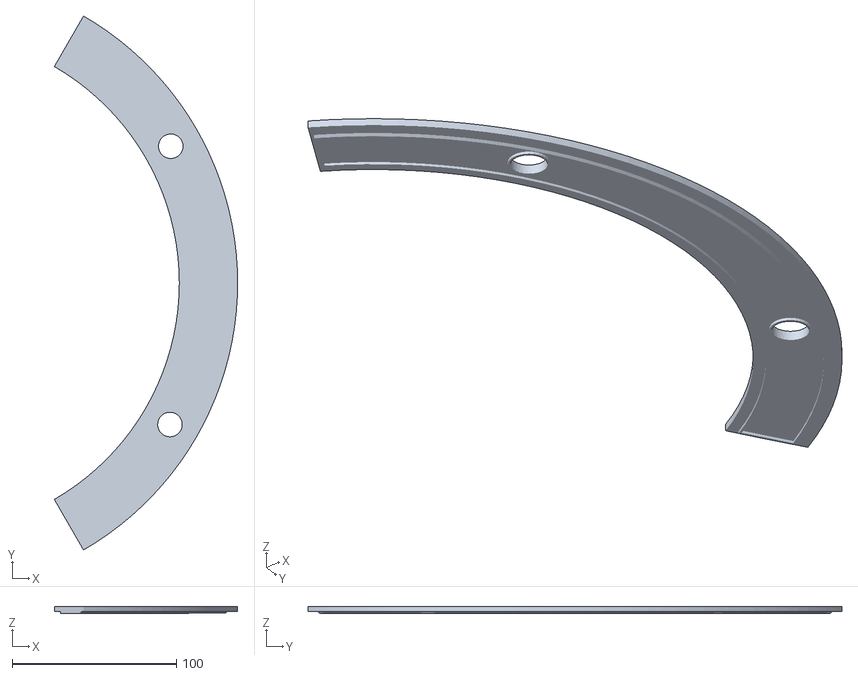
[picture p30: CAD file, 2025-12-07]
STLs/MainSliceCover.stl
111.5 x 324.8 x 4.00

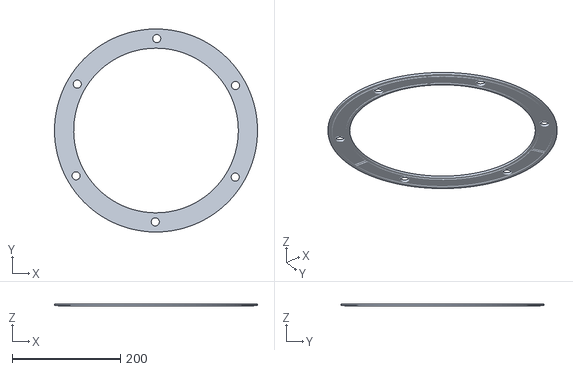
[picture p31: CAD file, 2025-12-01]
STLs/FullBalastCover.stl
374.9 x 375.0 x 4.00

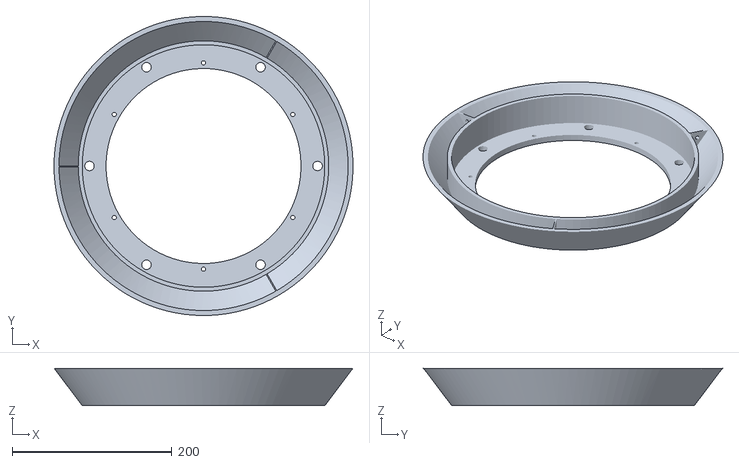
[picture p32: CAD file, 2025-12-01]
STLs/FullBallast.stl
374.9 x 375.0 x 47.0

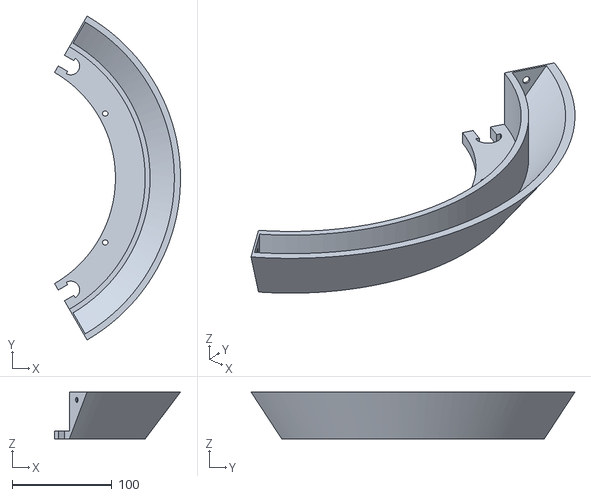
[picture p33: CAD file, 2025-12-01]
STLs/MainSlice.stl
126.3 x 324.8 x 47.0

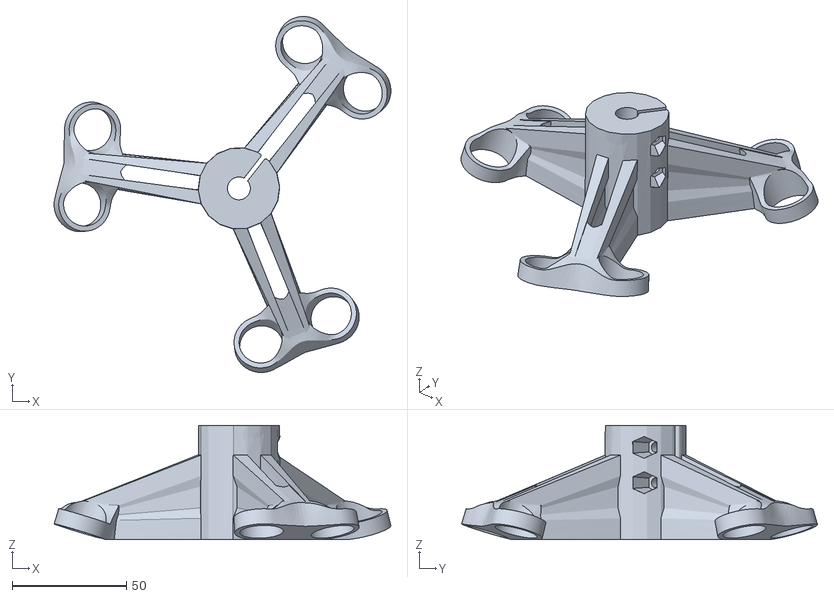
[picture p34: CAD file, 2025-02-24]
BMM/Halo-BMM-1-Piece-9.525MM-Shaft-v1.20.stl
147.6 x 156.0 x 50.0

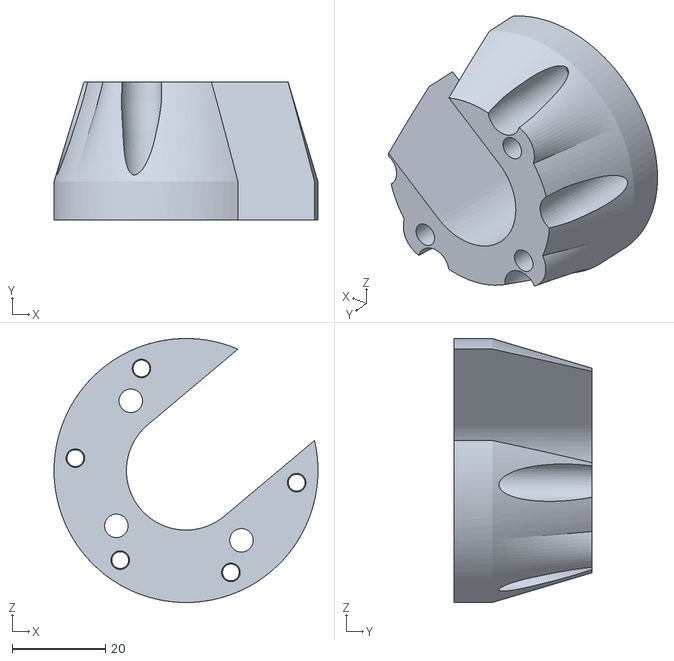
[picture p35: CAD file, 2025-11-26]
Frame/DriveHub_JoeDriveV2-Axle-Mount1inEasyInsert.stl
56.5 x 29.5 x 56.5

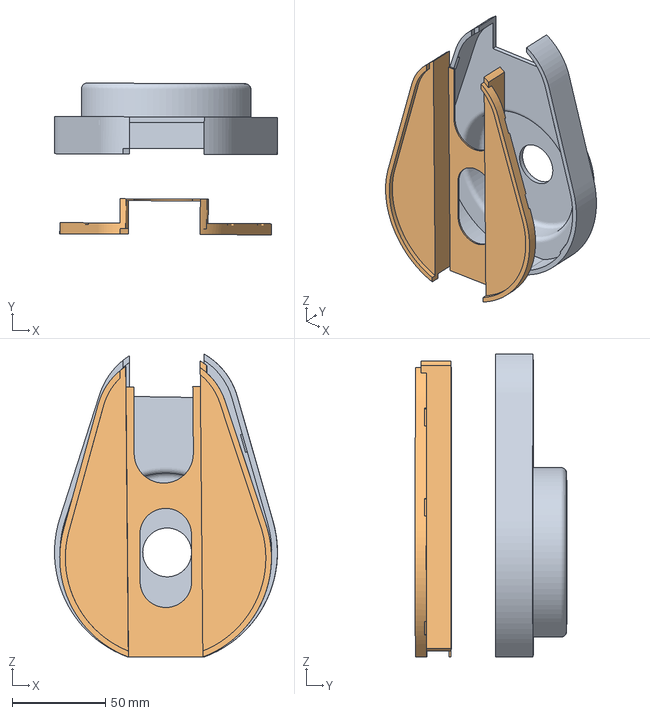
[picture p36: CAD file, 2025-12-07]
STLs/DriveSystem_Gear/OutsideGearCasing.3mf
119.7 x 81.5 x 162.6 mm
OutsideGearCasing.stl
InsideGearCasing.stl

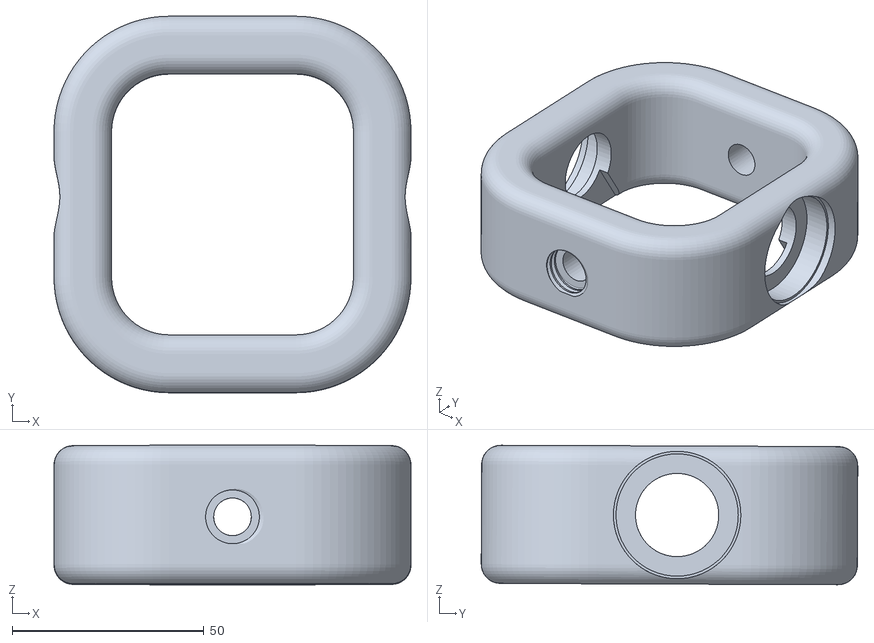
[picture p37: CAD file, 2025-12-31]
STLs/HeadTiltCoupler.stl
93.0 x 98.1 x 36.3

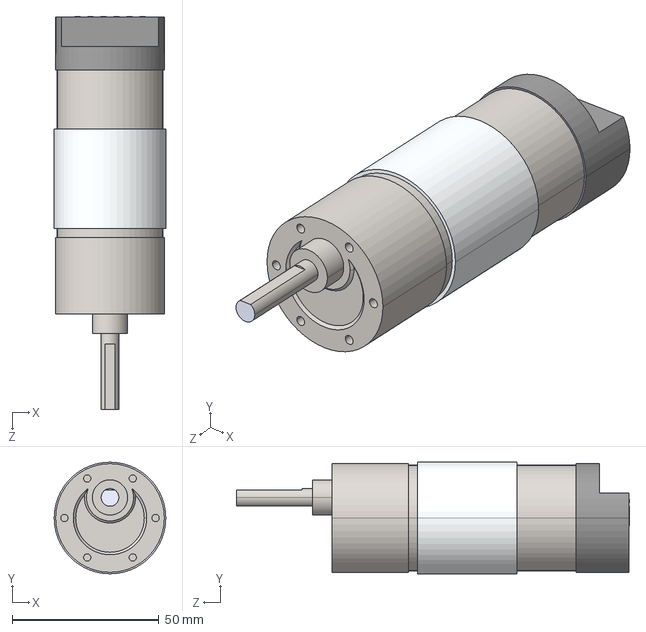
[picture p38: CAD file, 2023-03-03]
Support Hardware Step Files/am-3103 NeveRest 60.STEP
38.0 x 38.0 x 133.7 mm

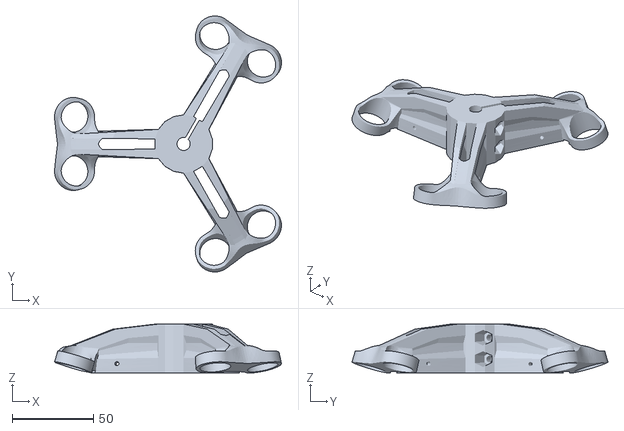
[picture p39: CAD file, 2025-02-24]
BMM/Halo-BMM-8MM-v1.3.00-Joes-Drive-Mk-2 (1).stl
139.5 x 157.3 x 30.0

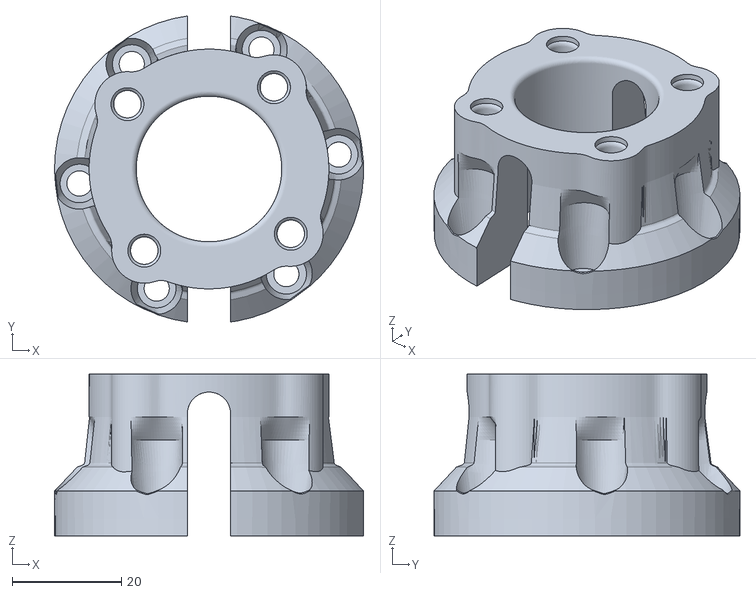
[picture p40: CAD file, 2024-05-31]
Frame/Drive_Hub_JoeDriveV2-Axle-Mount 1in-Axle v4.0.stl
56.4 x 55.9 x 29.5

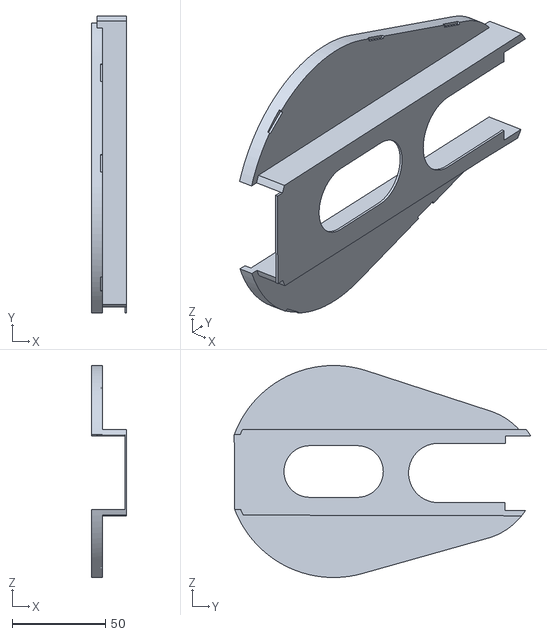
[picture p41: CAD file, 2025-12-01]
STLs/DriveSystem_Gear/InsideGearCasing.stl
19.0 x 158.9 x 113.6

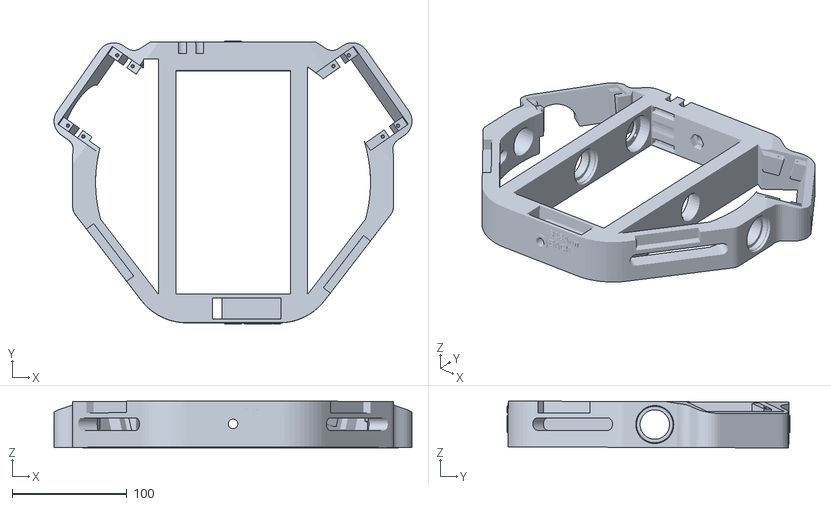
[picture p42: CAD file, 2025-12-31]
STLs/Gantry_140000320032_V2.stl
312.5 x 247.1 x 41.0

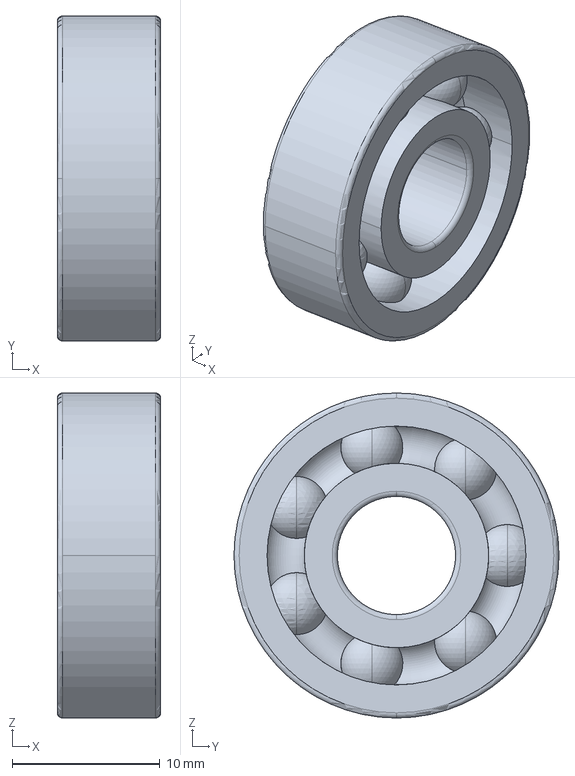
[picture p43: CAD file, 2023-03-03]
Support Hardware Step Files/bearing_608zz.stp
7.00 x 22.0 x 22.0 mm

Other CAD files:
BMM/DMM_Bearing.stl
STLs/BatteryHarness Cover.stl
STLs/DriveSystem_Gear/Drive Gear (94 teeth) 1302HUB.stl
Support Hardware Step Files/ROBOTZONE - PLANETARY GEAR MOTOR -638318.SLDPRT
BMM/10to12ForBMM.stl
BMM/Dshaft.stl
STLs/BatteryHarness.stl
STLs/CouplerPin.stl
STLs/CouplerPin_v2.stl
STLs/CouplerScrew_v2.stl
STLs/DriveSystem_Gear/Drive Gear (47 teeth) 1302HUB.stl
STLs/DriveSystem_Gear/Drive Gear (47 teeth) LEGACY.stl
STLs/DriveSystem_Gear/Drive Gear (94 teeth) LEGACY.stl
STLs/DriveSystem_Gear/Motor Gear (26 teeth) LEGACY.stl
STLs/DriveSystem_Gear/OutsideGearCasing.stl
STLs/FlyWheelArm.stl
STLs/FlyWheelLargeGear.stl
STLs/FlyWheelSmallGear.stl
STLs/Gantry Gear (53 teeth).stl
STLs/Gantry.stl
STLs/HeadTiltMast.stl
STLs/HeadTiltMastHall.stl
STLs/HeadTiltMastHall_10x5rd_12x5sq_V2.stl
STLs/HeadTiltMast_DRV5032_v2.stl
STLs/HeadTiltMast_Hall.stl
STLs/HeadTiltMast_Hall_QuicSensor.stl
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

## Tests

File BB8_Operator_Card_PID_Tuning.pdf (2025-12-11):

# Z■Class BB■8 — Operator Card (v9.1)

Live PID Tuning & Calibration — PS3 Move Navigation Controllers

Controllers: Drive = Right controller (lx/ly, D■pad, PS, X/O), Dome = Left controller (lx/ly, D■pad, PS)

Enter Pitch Tuning: Hold PS + UP (Drive) for 3s → Pitch PID (KP → KD → KI).
Enter Roll (S2S) Tuning: Hold PS + RIGHT (Drive) for 3s → Roll PID (Pk2 → Dk2 → Ik2).
Cancel Tuning: Hold PS + DOWN (Drive) for 3s → Restore persisted gains, neutralize outputs.
During tuning: Joysticks, sounds, dome, flywheel are disabled. Use D■pad UP/DOWN + X (store/advance).

## Pitch (Drive) PID Stages

Stage 1 — KP | Start KP=45.0, KI=0, KD=0; autoBalance OFF to see pure P. UP/DOWN: step ±1.0. X: store KP with 25% safety reduction, persist, advance to KD.
Stage 2 — KD | autoBalance ON to observe damping. UP/DOWN: step ±1.0. X: store KD, persist, advance to KI.
Stage 3 — KI | UP/DOWN: step ±0.1. X: store KI, persist, exit tuning.

## Roll (S2S) PID Stages

Stage 1 — Pk2 | Start Pk2=45.0, Ik2=0, Dk2=0. UP/DOWN: step ±1.0. X: store Pk2 with 25% reduction, persist, advance to Dk2.
Stage 2 — Dk2 | S2S auto■balance active for lateral damping observation. UP/DOWN: step ±1.0. X: store Dk2, persist, advance to Ik2.
Stage 3 — Ik2 | UP/DOWN: step ±0.1. X: store Ik2, persist, exit tuning.

Calibration (3■sec holds)
- SAVE: Hold UP+UP (both controllers) → Saves potOffset, pitchOffset, rollOffset to Preferences.
- RESET: Hold DOWN+DOWN (both) → Zeros offsets and persists.
Keys used: potOffset / pitchOffset / rollOffset.

Persistence & Cancel
- Stored gains: kp_pitch, kd_pitch, ki_pitch, pk2, dk2, ik2 in Preferences.
- PS+DOWN cancel restores persisted gains, disables auto■balance, and neutralizes drive/S2S PWM immediately.

Recommended Debug Combos
- Calibration: DEBUG_CALIBRATION + DEBUG_COMPACT
- PID Tuning: DEBUG_S2S_MODE + DEBUG_MOTOR_OUTPUT + DEBUG_COMPACT
- Controller: DEBUG_JOYSTICK + DEBUG_COMPACT

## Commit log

2023-03-06 Completed headtilt fitting
    [TiltCoupler.stl, TiltCouplerPin.stl, TiltMast.stl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]
2023-03-06 Initial Version
    Will require some adjustments for the battery tray due to needing supports - will add a large 30degree angle to allow for no supports.
    [Battery Tray.stl, ElecBase.stl, FliyWheelBigGear.stl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]
2023-03-07 Updated Tray to support less support
    [Battery Tray.stl]
2023-03-07 Main Gantry
    [FlywheelDriveArm.stl, MainGantry.stl, S2SDriveArm.stl]
2023-03-07 Removed rogue tabs
    [Battery Tray.stl]
2023-03-16 Updated v2 Arm Assemblies
    [FlywheelArm.stl, S2SArm.stl, S2SLargeGear.stl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]
2023-03-16 Applied v2 of the headtilt assembly
    [HeadTiltCoupler.stl, HeadTiltMast.stl, HeadTiltMotorCoupler.stl]
2023-03-16 Gantry Assembly v2 applied
    [Gantry.stl, S2SLargeGear.stl]
2023-03-16 FlyWheel Assembly v2 Applied
    [BatteryCompartment.stl, FlyWheelLargeGear.stl, FlyWheelSmallGear.stl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]
2023-03-16 Latest SHADOW Board
    All Components to support Z-ClassDrive
    [Astromech v2 mainboard Electronics Design.f3z]
2024-02-15 Updated to account for 3D printer accuracy
    Added .05 to all holes
    [Gantry.stl, S2SLargeGear.stl]
2024-05-05 Final STLs
    [10to12ForBMM.stl, BatteryCompartment.stl, DMM_Bearing.stl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]
2024-05-05 V8.2 Integrated Board
2024-05-05 Latest v8.2 board revisions
2024-05-05 All PCB boards are refreshed as of May 2024
2024-05-05 Added v8.2 board info
2024-05-08 New HeadTilt Assembly
    [CouplerPin.stl, HeadTiltCoupler.stl, HeadTiltMast.stl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]
2024-05-18 Improved space between frame and the coupler
    Reduced width
    [HeadTiltCoupler.stl]
2024-05-31 v2 to Vonjet hubs
    [Drive_Hub_JoeDriveV2-Axle-Mount 1in-Axle v4.0.stl]
2025-04-18 Update servos.ino
    Moved to
    - Modularization:- The use of helper functions (mapJoystickToAngle, easeAngle, adjustPitch, adjustRoll, etc.) ensures clarity and avoids redundant code.
    - applyReverseLogic neatly handles reversing inputs and tilt angles when reverseDrive is enabled.
    - Servo Constraints:- Parameterizing the servo constraints (LEFT_SERVO_MIN, LEFT_SERVO_MAX, etc.) makes the code more flexible and prevents magic numbers.
    - Pitch and Roll Adjustments:- The adjustPitch and adjustRoll functions properly compensate for pitch and roll deviations, scaling corrections dynamically using map and constrain.
    - Smooth Movement:- smoothServoMovement includes safeguards for division by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
2025-11-01 V3 Drive Updates All Tested for functionality
    Includes gear driven S2S potentiometer readings
    Supports associated SHADOW v8.2-V9 boards
    [BatteryCompartment.stl, CouplerPin.stl, Electronics.stl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]
2025-11-01 KISS version of the PCB supporting hardware Noise
    This is improved version supporting hardware noise dampening for DFplayer mini, servos and encoder on the dome spin.
2025-11-01 Cleaner Code supporting future v8.7 board changes
    This is a no hassle control for the primary ESP32 Board
2025-11-01 Supports clean servo and encoder communications with no jitter
    This is a rock solid version controling the servo twitches and encoder readings - no automated dome turning as yet
2025-11-03 Added hole for lith bat with charging connectors
    Increased the outer lock down holes to allow screws to slip through and added hole near SHADOW board to allow charging adapter to be exposed to system for adaption to charging through frame.
    [Electronics.stl]
2025-11-07 Move to i2c communications between ESP32 and 32u4
2025-11-10 Bottom Ballast including Battery and Electronics
    [BatteryHarness Cover.stl, BatteryHarness.stl]
2025-11-11 Updated slots to trap and hold axles
    [HeadTiltCoupler.stl]
2025-11-11 Minimum Harness and Electronics plates
    [BatteryHarness.stl]
2025-11-26 New Drive System alternate to chain drive
    This provides options for those finding it difficult to source the correct parts for the chain drive pully, this drive gear system is a perfect mesh and casing to protect the gears. There are 2 options here, a high resolution but slower gear ratio or a much quicker less accurate ratio,
    [Drive Gear (47 teeth) 1302HUB.stl, Drive Gear (47 teeth) LEGACY.stl, Drive Gear (94 teeth) 1302HUB.stl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]
2025-11-26 Easy insert for drive
    This allows quick insert of the drive system without mounting the hardware to the adapter to the frame.
    add the adapter to the body and then insert the drive into the adapter when ready.
    [DriveHub_JoeDriveV2-Axle-Mount1inEasyInsert.stl]
2025-12-01 Complete V3 Parts
    Completed V3 Parts supporting either Chain or Gear Drive System(s)
    [BatteryHarness Cover.stl, BatteryHarness.stl, Coupler.stl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]
2025-12-01 Potentiometer Gears
    Support S2S tracking with potentiometer gears
    [Gantry Gear (53 teeth).stl, Pot Gear (50 teeth).stl]
2025-12-01 Gear Drive System
    This supports Gear system drive train
    [Drive Gear (47 teeth) 1302HUB.stl, Drive Gear (47 teeth) LEGACY.stl, Drive Gear (94 teeth) 1302HUB.stl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]
2025-12-01 Gear Drive System
    Supports Gear based drive system
    [Drive Gear (47 teeth) 1302HUB.stl, Drive Gear (47 teeth) LEGACY.stl, Drive Gear (94 teeth) 1302HUB.stl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]
2025-12-05 i2C code to support PCB 8.9b or c
    This is inter board communications to support adapting the DFplayer mini to the 32u4 board to allow MP4 playing as well as offer configuration, tuning and changes to be applied off first boot state o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
2025-12-05 ESP32_Primary_v8_9b_i2c_RC
    JOE'S DRIVE v8.9b — ESP32 MASTER — FINAL & COMPLETE
    - Serial1 → IMU Board (unchanged, EasyTransfer)
    - I2C → DOME CONTROLLER (32u4 with DFPlayer + ALL servos)
    - Uses SharedStructs.h for identical data layout
    - 100% identical behavior to v8.7 however smoother support for motors, servos and feedback
2025-12-05 BB8_v8_9c_i2c_RC
    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
2025-12-05 MAINBOARD_v8_9b_i2c
    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
2025-12-07 Corrected Files
    [HeadTiltCouplerPin_x2.stl, S2SGear_LargeGear.stl, S2SGear_SmallGear(LEGACY).stl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]
2025-12-07 Corrected Gear
    [S2SGear_LargeGear.stl]
2025-12-07 Corrected STL files
    [HeadTiltCoupler.stl, HeadTiltMotorCoupler.stl, MainSliceCover.stl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]
2025-12-08 Fina DFPLAYER PCB board
2025-12-11 mainboard v9.1
    Final design allowing for proper capacitor, resistance and overall agility
2025-12-31 Final Version 9.15
    Supports proper signal voltage regulation, DFplayer and stability enhancements
2025-12-31 Version Updates to support discontinued couplers and other items
    [BatteryHarness Cover.stl, CouplerPin_v2.stl, CouplerScrew_v2.stl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]
2025-12-31 Updated for screw on pin types
    [HeadTiltCoupler.stl]
2025-12-31 Updated to support working PCBs
    Main updated to 9.15, dome and IMU didnt change
2025-12-31 Refreshed firmware for supported boards
2026-08-27 v10 BETA board - this can be used w Gear drive
    This is to be installed opposite of the drive gear system. This sits inside the casing and uses new board designs which include RP2350 and ESP32.
2026-08-27 Docs: this repo is the HARDWARE half — all control software is Z-ClassControlSystem
    README rewritten: hardware-first (mechanics, PCBs incl. v10 compact BETA, BOM, wiring), prominent pointer to Z-ClassControlSystem for firmware/bb8 CLI/releases (Setup-BASIC / Setup-MAX) and the wiki (First-Time Setup, How-To, Runbook, Rig Tuning, Assembly); fixed the broken hero image; folder-by-folder layout table; legacy notes (v9.15 SourceFiles superseded by RC4 and being removed, PID operator card obsolete). SourceFiles/README + PCB/README pointer pages added.
2026-10-03 Updated BOM for latest Drive System Changes
    This supports no longer supported or available parts
    [Z-Drive_JoesDrive_V2 BOM.xlsx]
